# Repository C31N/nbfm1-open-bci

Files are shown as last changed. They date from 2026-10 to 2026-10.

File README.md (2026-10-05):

<!-- SPDX-License-Identifier: AGPL-3.0-only -->
# NBFM-1 Open BCI Stack






\n

Open-source research platform for a multimodal, non-invasive brain-computer interface built around three independently useful layers:

1. **NBFM-1** — an asynchronous neural foundation model with a millisecond-scale EEG/MEG fast path and a slower fNIRS context path.
2. **P1/P2 edge stack** — local inference, TensorRT/ONNX deployment, CUDA Graph-compatible I/O, encrypted local transport, intent gating, privacy zeroization, telemetry and systemd services.
3. **EEG128-TDM** — an ultra-low-cost 128-channel differential EEG acquisition architecture using paired 16:1 analog multiplexers, an 8-channel simultaneous-sampling delta-sigma ADC and an RP2040-class controller.

> **Research use only.** This repository does not claim medical-device certification, diagnostic suitability, prosthesis safety certification or validated free-form thought decoding. The `<5 ms` value is a compute-latency target measured after the required neural signal window is available, not a claim about neurophysiological response time.

## Defensive publication

The enabling technical disclosure is in [`PATENT_DISCLOSURE.md`](PATENT_DISCLOSURE.md). The document is intentionally explicit about timing, packet formats, signal routing, filter-settling handling, asynchronous multimodal fusion and privacy gating so the disclosed combinations can be independently implemented and searched as public technical literature.

A repository commit is evidence, not magic. For a stronger publication record, publish a signed release, generate the repository SHA-256 manifest and archive that release in a DOI-backed repository such as Zenodo. See [`docs/PUBLICATION_PROCEDURE.md`](docs/PUBLICATION_PROCEDURE.md).

## System architecture

```mermaid
flowchart LR
    EEG["128-ch EEG<br/>1 kHz after decimation"] --> FAST["Fast neural path"]
    MEG["OPM-MEG<br/>geometry embeddings"] --> FAST
    FNIRS["fNIRS<br/>20 Hz short/long separation"] --> SLOW["Slow context encoder"]
    FAST --> NBFM["NBFM-1 causal transformer"]
    SLOW --> XATTN["Cross-attention"]
    XATTN --> NBFM
    NBFM --> MOTOR["Motor Gaussian head<br/>mu + sigma"]
    NBFM --> GATE["Intent gate<br/>P(intent)"]
    NBFM --> CTC["Phonemic CTC head"]
    GATE --> PRIVACY["Local-first privacy gate"]
    CTC --> PRIVACY
    PRIVACY --> ENC["AES-256-GCM local export"]
    MOTOR --> SAFETY["Rate/uncertainty limiter"]
    ENC --> AGENT["Local agent adapter"]
    SAFETY --> ACT["Cursor / bench actuator interface"]
```

### EEG128-TDM acquisition path

```mermaid
flowchart LR
    E["128 differential EEG channels<br/>256 electrode conductors"] --> M["8 banks x paired 16:1 MUX<br/>16 CD74HC4067 total"]
    M --> B["16 low-noise unity buffers"]
    B --> A["ADS131M08<br/>8 simultaneous 24-bit delta-sigma channels<br/>32 kSPS"]
    A --> R["RP2040<br/>SPI + DMA"]
    R --> D["16-position demultiplex<br/>settling discard + averaging"]
    D --> O["128 channels x 250 SPS<br/>offset/gain correction"]
```

## Hardware revision status

The repository contains **EEG128-TDM Revision A0** KiCad/BOM/CPL/netlist sources, but A0 is **not released for fabrication or human-connected use**. The board still requires independent routing and footprint verification followed by clean KiCad 8 ERC/DRC and the safety release gates in [`docs/SAFETY_COMPLIANCE.md`](docs/SAFETY_COMPLIANCE.md).

The manufacturing exporter is fail-closed: [`hardware/eeg128-tdm/generate_manufacturing.py`](hardware/eeg128-tdm/generate_manufacturing.py) refuses to generate Gerber output while [`RELEASE_STATUS.json`](hardware/eeg128-tdm/RELEASE_STATUS.json) contains an unmet release gate.

## Privacy-state machine

```text
LOCKED --explicit local arm--> ARMED --P(intent) >= T_gate--> DECODING
   ^                          |                              |
   |                          +--below threshold------------+
   +---------------- timeout / lock / fault ----------------+
```

Speech logits remain local. When the gate is closed, the export tensor is replaced with a fixed-shape zero tensor before encryption. Frame dimensions therefore do not reveal whether a private speech hypothesis existed.

## Physical hardware release status

The repository contains the A0 KiCad project, logical netlist, BOM/CPL and fail-closed manufacturing tooling, but **A0 is not released for fabrication or human-connected use**.

The current audited EDA state has placement/net assignments but not completed copper routing, and the current schematic is a connectivity index rather than a complete instantiated circuit schematic. The authoritative release blockers are machine-readable in `hardware/eeg128-tdm/RELEASE_STATUS.json`.

Run:

```bash
python3 hardware/eeg128-tdm/validate_eda.py
```

Manufacturing export remains blocked until the independent physical release gates are satisfied.

See:

- `hardware/eeg128-tdm/EDA_AUDIT.md`
- `docs/SAFETY_COMPLIANCE.md`
- `docs/AUDIT_2026-10-05.md`

## Quick start

```bash
chmod +x deploy_bci_stack.sh
./deploy_bci_stack.sh
```

Run the latency auditor after inference and bridge services are healthy:

```bash
python3 bin/audit_latency.py \
  --json reports/latency-audit.json \
  --html reports/latency-audit.html
```

A benchmark is considered successful only when the measured P99 meets the configured threshold. The badge above states the **target**, not an unmeasured result.

## Licensing

Hardware design source and firmware are licensed under **CERN Open Hardware Licence Version 2 — Strongly Reciprocal (`CERN-OHL-S-2.0`)**. The NBFM-1 software architecture, inference stack, privacy gate, deployment code, scripts and project documentation are licensed under **GNU Affero General Public License v3.0 only (`AGPL-3.0-only`)**.

## Citation

Machine-readable citation metadata is in [`CITATION.cff`](CITATION.cff).

## Security

Neural raw data, derived embeddings, decoded speech, session keys, model weights and device-specific calibration can be sensitive. Never commit them. See [`SECURITY.md`](SECURITY.md) and the enforced exclusions in [`.gitignore`](.gitignore).

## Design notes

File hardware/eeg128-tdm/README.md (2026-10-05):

<!-- SPDX-License-Identifier: CERN-OHL-S-2.0 -->
# EEG128-TDM Hardware Source — Revision A0

## Architecture

```text
128 differential logical EEG channels
= 256 subject/electrode conductors
        |
        v
8 banks x 16 logical channels
        |
        v
16 paired CD74HC4067-class 16:1 multiplexers
        |
        v
16 TLV9064-class unity buffers
        |
        v
ADS131M08-class 8-channel simultaneous delta-sigma ADC
32 kSPS, external 8.192-MHz clock
        |
        v
RP2040 SPI1 + DMA
        |
        v
4 post-switch conversions discarded
4 late conversions averaged
        |
        v
128 logical channels x 250 SPS
```

## Source files

| File | Purpose |
|---|---|
| `design_spec.yaml` | Human-readable electrical/stack-up source of truth |
| `NETLIST.csv` | Detailed endpoint-to-endpoint logical connectivity |
| `BOM.csv` | JLCPCB/LCSC-oriented bill of materials |
| `CPL.csv` | JLCPCB-oriented component placement |
| `eeg128-tdm.kicad_sch` | KiCad 8 schematic/connectivity index |\n| `generate_schematic.py` | Deterministically generates a 640-component KiCad connectivity schematic from PCB pad/net assignments |
| `eeg128-tdm.kicad_pcb` | KiCad 8 four-layer A0 placement/net board |
| `eeg128-tdm.kicad_pro` | KiCad project |
| `validate_eda.py` | Source/BOM/CPL/net validation |
| `generate_manufacturing.py` | Fail-closed KiCad 8 ERC/DRC/Gerber/JLCPCB export |
| `RELEASE_STATUS.json` | Machine-readable fabrication/human-use release gates |

## Current fabrication status

**Revision A0 is not released for fabrication.**

The board source currently contains component placement and logical pad-to-net assignment for A0 design review, but the copper routing is not complete, the KiCad schematic is presently a connectivity index rather than a fully instantiated circuit schematic, and generated footprint land patterns have not been independently verified. `RELEASE_STATUS.json` therefore keeps `fabrication_release=false`.

This is intentional. A large human-connected mixed-signal board must not become orderable merely because source files exist.

The manufacturing exporter refuses to run until all release gates are true.

## Validation

Repository-level structural validation:

```bash
python3 hardware/eeg128-tdm/validate_eda.py
```

Release validation additionally requires KiCad CLI 8:

```bash
cd hardware/eeg128-tdm
python3 validate_eda.py --kicad-release-checks
```

After independent routing/footprint/safety review and only after `RELEASE_STATUS.json` is intentionally signed off:

```bash
python3 generate_manufacturing.py
```

The script executes KiCad ERC and PCB DRC before exporting Gerber, drill and position data. Any failed release gate or KiCad violation stops the export.

## Four-layer intent

```text
L1  F.Cu   analog inputs, MUX/buffer/ADC and short local digital routes
L2  In1.Cu continuous return plane; analog/digital domains managed by placement/current paths
L3  In2.Cu 3V3A / 3V3D / VCM distribution
L4  B.Cu   high-speed digital, USB and controller-side routing
```

Do not create arbitrary AGND/DGND moat cuts that force return currents to detour. Domain control is primarily by placement/routing, with the ground-domain connection deliberately reviewed at the ADC/power boundary.

## Safety

This is research hardware, not IEC 60601-certified equipment.

No human-connected use is authorized by this repository revision. Follow `docs/SAFETY_COMPLIANCE.md`. In particular, a subject-connected analog domain must not have an uncontrolled galvanic path to mains-referenced equipment.

## License

Hardware source is covered by `CERN-OHL-S-2.0`.

## Package and grounding audit

### ADS131M08IPBSR

Use the TI **PBS** mechanical drawing as the authoritative footprint reference. The package has a nominal 5 mm square body with 0.50 mm lead pitch and approximately 7 mm overall lead span. Distributor summaries can describe these dimensions differently; release review must use the manufacturer drawing.

### Ground plane

The current logical source uses separate `AGND` and `DGND` names while the intended PCB strategy calls for a continuous return plane. This conflict must be resolved before routing release. Do not introduce an arbitrary split-plane slot solely to preserve naming.

### Internal reference

The selected low-noise reference network must be reviewed explicitly before A0 fabrication. The present logical netlist records `ADC_REFIN` as unpopulated; for EEG noise optimization, provision for local REFIN filtering must be evaluated against TI guidance and the chosen converter mode.

See `EDA_AUDIT.md` and `RELEASE_STATUS.json`.

## Generated connectivity schematic

The deterministic generator can materialize every PCB/BOM component and every assigned pad net into a KiCad 8 schematic representation:

```bash
python3 generate_schematic.py
```

Default output:

```text
eeg128-tdm.generated.kicad_sch
```

It uses real component references and PCB pad numbers and emits local labeled wire stubs for assigned nets. It intentionally uses conservative generic passive-pin symbols. Therefore it is useful for reproducible connectivity review and schematic/PCB parity, but it does **not** replace manufacturer-symbol pin-type review or independently establish ERC/fabrication readiness.

Only after review may it replace the primary schematic:

```bash
python3 generate_schematic.py --replace-primary
```

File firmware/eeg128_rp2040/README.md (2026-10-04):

<!-- SPDX-License-Identifier: CERN-OHL-S-2.0 -->
# EEG128-TDM RP2040 Firmware

This firmware drives the Rev A0 EEG128-TDM acquisition concept:

- 8 differential ADC paths;
- 16 shared MUX addresses;
- ADS131M08-class converter at 32 kSPS;
- four conversions discarded after each MUX change;
- four late conversions averaged;
- 128 logical samples per frame at 250 frames/s;
- SPI1 + DMA acquisition;
- per-logical-channel startup offset calibration;
- binary 1152-byte P1/P2 packets with CRC32C.

## RP2040 pins

| Function | GPIO |
|---|---:|
| MUX A0..A3 | 2..5 |
| MUX enable | 6 |
| ADS DOUT / SPI1 RX | 8 |
| ADS CS | 9 |
| ADS SCLK / SPI1 SCK | 10 |
| ADS DIN / SPI1 TX | 11 |
| ADS DRDY | 12 |
| ADS SYNC/RESET | 13 |

The ADS clock is supplied by the board's dedicated 8.192-MHz CMOS oscillator.

## Build

```bash
export PICO_SDK_PATH=/path/to/pico-sdk
mkdir -p build
cd build
cmake ..
cmake --build . -j
```

The firmware is research firmware and does not authorize human-connected use. Follow `docs/SAFETY_COMPLIANCE.md`.

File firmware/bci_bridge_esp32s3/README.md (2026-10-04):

<!-- SPDX-License-Identifier: CERN-OHL-S-2.0 -->
# BCI Device Firmware

Firmware in this tree implements hardware acquisition/bridge functions, including deterministic sensor sampling, CRC32C framing, transport and device-side timing. It is licensed as hardware Source under `CERN-OHL-S-2.0`.

The bridge packet extension uses the common 128-byte BCI packet header plus a compact payload for low-cost test hardware. Production 128-channel acquisition uses the 4096-byte DMA-slot protocol disclosed in `PATENT_DISCLOSURE.md`.

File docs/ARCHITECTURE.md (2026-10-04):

<!-- SPDX-License-Identifier: AGPL-3.0-only -->
# Architecture Summary

## Fast path

EEG and OPM-MEG are sampled and preprocessed independently of the fNIRS hemodynamic timescale. Causal patch encoders produce aligned fast tokens. OPM-MEG tokens include sensor-pose embeddings.

## Slow context path

fNIRS remains at its native slow update rate. Long-separation and short-separation measurements feed a slow context encoder. Fast tokens cross-attend only to context already available at the inference timestamp.

## Decoder heads

NBFM-1 exposes a Gaussian motor head (`mu`, `log_sigma`), scalar intent gate and time-distributed CTC speech logits.

## Privacy boundary

Speech export requires both local `ARMED` state and an intent threshold. Closed-gate speech tensors are replaced by fixed-shape zero tensors before AEAD encryption. This avoids a message-length side channel.

## Hardware front end

The EEG128-TDM architecture maps eight 16-channel differential banks through sixteen paired analog multiplexers and sixteen buffers into eight simultaneous ADC inputs. At 32 kSPS, each 250 us slot contains enough conversions to discard digital-filter/analog settling and retain later conversions for the logical 250 SPS channel sample.

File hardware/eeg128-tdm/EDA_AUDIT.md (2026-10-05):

<!-- SPDX-License-Identifier: CERN-OHL-S-2.0 -->
# EEG128-TDM A0 EDA Release Audit

## Status

**NOT RELEASED FOR FABRICATION**

This document records the engineering state of the physical A0 source. It intentionally prevents “source exists” from being mistaken for “board is production-ready”.

## Current machine-observed source state

After deterministic materialization and native KiCad 8.0.9 validation on 2026-10-05:

```text
KiCad schematic:
  instantiated circuit symbols: 640
  electrical wire stubs:         1875
  primary schematic parses:      yes
  native netlist export:         yes

Native ERC report:
  total findings:                3338
  errors:                        183
  warnings:                      3155

KiCad PCB:
  footprints:                    640
  copper tracks/segments:        0
  vias:                          0
  copper zones:                  0
  four copper layers declared:   yes

Native PCB DRC report:
  unconnected errors:            499
  DRC violations:                1503
  DRC errors:                    897
  DRC warnings:                  606
  schematic-parity items:        0
```

The primary schematic is now a KiCad-loadable, deterministic 640-component connectivity schematic generated from the PCB pad/net assignments. It uses conservative generic passive pin types and therefore still requires manufacturer-symbol/pin-type review before `schematic_complete` can be set true.

The PCB remains a placement/net-assignment review artifact. It is not routed.

## A0 architecture retained

```text
256 electrode conductors
        |
        v
8 differential banks x 16 logical channels
        |
        v
16 x CD74HC4067
        |
        v
16 low-noise buffer channels
        |
        v
ADS131M08, 8 simultaneous differential channels
        |
        v
32 kSPS conversion stream
        |
        v
RP2040 SPI/DMA
        |
        v
settling discard + averaging
        |
        v
128 logical channels x 250 SPS
```

## ADS131M08 package

Part:

```text
ADS131M08IPBSR
TI package drawing: PBS
pins: 32
body: approximately 5 x 5 mm
lead pitch: 0.50 mm
outer lead span: approximately 7 x 7 mm
```

The project shall verify the footprint against the TI PBS mechanical drawing before setting `footprints_verified=true`.

## Grounding release decision

Current logical sources use `AGND` and `DGND` names while the layout strategy calls for a continuous return plane.

Before copper generation, the designer must resolve this explicitly. Preferred A0 direction:

- continuous low-impedance ground plane;
- analog and digital current control by placement and routing;
- no arbitrary split-plane slot under the ADC;
- decoupling return loops kept local;
- digital clocks kept out of the electrode/MUX region.

## REFIN decision

The internal-reference network shall be explicitly reviewed before A0 fabrication. For low-noise operation, provision for a local 100 nF REFIN capacitor to the converter ground reference should be evaluated against the selected ADS131M08 operating mode and TI guidance.

## Mandatory release evidence

The following evidence must exist before manufacturing export is enabled:

- schematic ERC report;
- PCB DRC report;
- schematic/PCB parity report;
- footprint verification record;
- placement/orientation review;
- Gerber visual review;
- BOM/CPL cross-check;
- routing-complete evidence;
- ground strategy review;
- isolated bench bring-up procedure;
- noise and settling test plan;
- signed `RELEASE_STATUS.json` change.

## Prohibited shortcuts

Do not:

- set release flags true merely to make CI green;
- export/order the current unrouted PCB;
- infer electrical correctness from the presence of pad net names;
- treat distributor footprint drawings as authoritative over manufacturer package drawings;
- connect a human subject while USB, bench supplies, oscilloscopes or other earth-referenced equipment provide an uncontrolled galvanic path.

## Native KiCad 8 audit interpretation

The successful GitHub Actions job means KiCad 8.0.9 can parse the EDA sources and produce native reports. It does **not** mean ERC or DRC are clean.

ERC finding classes include:

- endpoint-off-grid warnings;
- generated-library symbol warnings;
- unconnected-pin errors;
- dangling-label errors.

PCB findings are dominated by the intentionally unrouted design and generated-footprint review state, including unconnected items, clearance/shorting, solder-mask, silkscreen and library-footprint findings.

Therefore `erc_passed=false`, `drc_passed=false`, `routing_completed=false` and `fabrication_release=false` remain mandatory.

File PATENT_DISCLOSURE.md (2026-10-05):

<!-- SPDX-License-Identifier: AGPL-3.0-only -->
# Defensive Publication and Enabling Technical Disclosure — NBFM-1 Open BCI Stack

## 1. Purpose, scope and public-availability statement

This document is an enabling defensive publication of technical architectures, timing methods, signal-processing arrangements, machine-learning structures, privacy mechanisms and deployment methods for a non-invasive multimodal brain-computer interface.

**Initial document preparation date:** 2026-10-04.\n\n**Legal/technical audit revision:** 2026-10-05.

**Repository:** `C31N/nbfm1-open-bci`.

This document is intended to make the disclosed combinations publicly searchable and reproducible technical literature when the repository is publicly accessible without confidentiality restrictions.

For United States patent-law analysis, public availability before the effective filing date may be relevant under 35 U.S.C. 102(a)(1), including a printed publication or other disclosure available to the public. For European patent-law analysis, Article 54(2) EPC defines the state of the art as everything made available to the public before the filing date by written or oral description, use, or any other way. An alleged documentary disclosure must also teach the relevant technical subject matter sufficiently for the skilled person to carry it out.

This file therefore distinguishes:

1. **preparation date** — the date written above;
2. **public-availability evidence** — public Git commit, tag, release, archive, DOI or equivalent record; and
3. **technical enablement** — concrete parameters, relationships, timing and implementation details below.

No statement in this repository guarantees that every later patent application concerning related subject matter will be refused or invalidated. Patentability depends on the actual later claims, effective filing/priority dates, applicable law, novelty, inventive step/non-obviousness, enablement and evidence of public availability. The objective is to create strong, independently verifiable prior-art evidence for the specific teachings disclosed here.

Public disclosure may also limit or destroy the publishers' own future patent rights in jurisdictions without an applicable grace period. Publication should therefore occur only after any desired patent strategy has been decided.

## 2. Legal prior-art framework and evidentiary limits

### 2.1 United States — 35 U.S.C. §102

Under 35 U.S.C. §102(a)(1), a claimed invention may lack novelty where, before its effective filing date, it was patented, described in a printed publication, in public use, on sale, or otherwise available to the public.

The statute contains exceptions, including certain disclosures addressed by §102(b). Accordingly, this publication does **not** assert that its existence automatically defeats every later United States patent claim. The relevant questions include the later claim language, effective filing date, derivation/origin, public availability, and whether this disclosure actually teaches every element required by the claim.

Official text:

https://uscode.house.gov/view.xhtml?req=granuleid:USC-prelim-title35-section102

### 2.2 European Patent Convention — Article 54

Article 54(2) EPC defines the state of the art as everything made available to the public before filing by written or oral description, use, or any other way.

EPO examination guidance further states that:

- there is generally no restriction on the geographical location, language or manner of public availability;
- a written disclosure is publicly available when members of the public could obtain knowledge of its content without a confidentiality duty; and
- documentary prior art must provide sufficient information for the skilled person to put the disclosed technical teaching into practice.

Official sources:

- https://www.epo.org/en/legal/epc/2020/a54.html
- https://www.epo.org/en/legal/guidelines-epc/2026/g_iv_1.html
- https://www.epo.org/en/legal/guidelines-epc/2026/g_iv_2.html
- https://www.epo.org/en/legal/guidelines-epc/2026/g_iv_7_5.html

### 2.3 Internet-publication evidence

A public repository can be evidence of an internet disclosure, but the legal effect of any particular Git commit, release, archive or timestamp is fact-specific.

For that reason this project preserves multiple independent evidence layers:

1. public Git commit identity;
2. immutable release tag where available;
3. SHA-256 manifest of the disclosed files;
4. public release archive;
5. independent archival record/DOI where available.

A later technical correction should be published as a new revision and should not rewrite the historical record of the earlier disclosure.

### 2.4 What this publication is intended to establish

The purpose is to provide an enabling, searchable technical disclosure of the specific combinations described below — including asynchronous fast/slow neural fusion, intent-controlled fixed-shape zeroization, and settling-aware differential TDM EEG acquisition.

The publication is **not** a representation that:

- all conceivable variants have been disclosed;
- all later patent claims are necessarily anticipated or obvious;
- the authors have freedom to operate under third-party patents;
- public disclosure creates a patent right for the project;
- a particular patent office or court is bound to reach a specified result.

## 3. Terminology

The following project terms are used for searchability and do not imply exclusive trademark or patent rights:

- **NBFM-1** — Neural Brain Foundation Model, revision 1;
- **Fast Neural Path** — causal EEG and/or OPM-MEG processing;
- **Slow Context Path** — native-rate fNIRS context processing;
- **Intent Gate** — an explicit probability-gated privacy and control boundary;
- **Fixed-shape zeroization** — replacing sensitive logits with a same-shape zero tensor before export;
- **EEG128-TDM** — 128-channel differential time-division-multiplexed EEG front end.

---

# PART I — ASYNCHRONOUS MULTIMODAL NEURAL FOUNDATION MODEL

## 4. Sensor domains and asynchronous clocks

A representative system contains:

- 128-channel EEG, nominally 1 kHz after acquisition decimation;
- OPM-MEG channels carrying position/orientation metadata;
- fNIRS at approximately 20 Hz using long- and short-separation source-detector measurements.

The modalities are deliberately **not** resampled into one artificial common-rate stream before representation learning.

```text
EEG 1 kHz -----+
               +--> causal fast encoders --> fast tokens --------+
OPM-MEG -------+                                                   |
                                                                   +--> NBFM-1
fNIRS 20 Hz --> slow encoder --> persistent context --> XATTN ----+
                                                                   |
                          +----------------------------------------+-----------+
                          |                                        |           |
                          v                                        v           v
                 Gaussian motor head                         Intent gate   CTC speech
```

At fast-path inference timestamp `t`, the model may use only slow-context measurements with acquisition timestamps `<= t`.

## 5. Causal EEG/MEG patch encoding

Representative fast inputs are:

```text
EEG: [batch, 128, T_fast]
MEG: [batch, C_meg, T_fast]
```

A representative causal patch encoder uses:

```text
Conv1D: kernel 17, stride 8, left-only padding
normalization
GELU
Conv1D: kernel 5, stride 2, left-only padding
normalization
GELU
D_model = 384
```

For kernel length `k` and dilation `d`, left padding is:

```text
P_left = d * (k - 1)
```

No future fast sample contributes to the current output token.

## 6. OPM-MEG geometry conditioning

For sensor `i` use:

```text
g_i = (x_i, y_i, z_i, nx_i, ny_i, nz_i)
```

where the first three components are position and the latter three are measurement-axis orientation.

A sensor-level affine conditioning may be:

```text
(alpha_i, beta_i) = MLP(g_i)
x_i' = x_i * (1 + lambda * tanh(alpha_i)) + eta * beta_i
```

A token-level geometry embedding may additionally be:

```text
e_geometry = mean_i(MLP_geometry(g_i))
Z_MEG' = Z_MEG + e_geometry
```

This explicitly separates physical sensor geometry from arbitrary channel numbering.

## 7. Slow fNIRS context

A representative 20-Hz fNIRS context sample contains:

```text
128 long-separation paths x 2 wavelengths
32 short-separation paths x 2 wavelengths
= 320 scalar values
```

A causal slow encoder produces:

```text
Z_slow: [batch, N_slow, D_model]
```

The most recent valid context remains available until a new fNIRS sample arrives. The fast path does not fabricate intermediate hemodynamic observations.

## 8. Asynchronous fast-query/slow-context cross-attention

For each fusion block:

```text
Q = Wq * Z_fast
K = Wk * Z_slow
V = Wv * Z_slow

Attention = softmax((Q * transpose(K)) / sqrt(d_head))
Z_fast' = Z_fast + Attention * V
```

The disclosed feature is the use of native-rate slow context as persistent memory while fast causal tokens provide queries. This differs from mandatory upsampling/concatenation of fNIRS to every EEG/MEG sample.

## 9. Representative NBFM-1 edge model

```text
D_model        = 384
heads          = 6
layers         = 6..8
FF multiplier  = 4
fast context   = hundreds to thousands of samples
slow context   = independently sized fNIRS history
edge precision = FP16 or validated INT8
```

Each block contains:

```text
pre-norm
--> causal fast self-attention
--> residual
--> fast-query / slow-context cross-attention
--> residual
--> feed-forward network
--> residual
```

## 10. Self-supervised pretraining

Pretraining can combine:

- masked temporal reconstruction;
- masked channel reconstruction;
- modality masking;
- geometry perturbation;
- cross-modal prediction;
- subject-contrastive learning;
- covariance/domain alignment;
- teacher-student latent reconstruction.

Representative total objective:

```text
L_total =
    lambda_masked      * L_masked
  + lambda_crossmodal  * L_crossmodal
  + lambda_contrastive * L_contrastive
  + lambda_domain      * L_domain
  + lambda_task        * L_task
```

## 11. Gaussian motor-intent head

The motor head emits:

```text
mu       = [vx, vy, vz, grip]
log_std  = [sx, sy, sz, sgrip]
```

with diagonal Gaussian interpretation:

```text
p(y | X) = Normal(mu, diag(exp(2 * log_std)))
```

A separate safety stage may implement:

```text
if P(intent) > T_motor and every std < std_max:
    u_safe = clamp(mu)
else:
    u_safe = 0
```

The AI decoder therefore does not directly command an actuator without uncertainty and safety checks.

## 12. Dedicated intent gate

The intent head computes a scalar probability:

```text
p_intent = sigmoid(w^T z + b)
```

Representative speech/privacy threshold:

```text
T_gate = 0.95
```

The intent output is explicitly used as a **privacy/export boundary**, not solely as another classification metric.

---

# PART II — LOCAL-FIRST ZERO-SIDECHANNEL PRIVACY

## 13. State machine

```text
LOCKED
  |
  | explicit local arm
  v
ARMED
  |
  | P(intent) >= T_gate
  v
DECODING
```

A high neural probability alone cannot arm a locked device. Explicit lock, timeout, watchdog or authentication failure may return the device to `LOCKED`.

## 14. Fixed-shape speech-logit zeroization

Let speech logits have shape:

```text
L: [T_speech, vocabulary]
```

Export rule:

```text
if local_state permits decoding and P(intent) >= T_gate:
    L_export = L
    speech_valid = 1
else:
    L_export = zeros_like(L)
    speech_valid = 0
```

The **shape and serialized field layout remain unchanged**. Zeroization occurs before encryption and before the data leaves the local inference boundary.

This design reduces straightforward content-presence and message-length side channels.

## 15. Local-first processing

Default path:

```text
neural sensors
--> local preprocessing
--> local NBFM inference
--> local intent/privacy gate
--> same-shape zeroization when closed
--> authenticated encryption
--> local authenticated consumer
```

Raw EEG/MEG/fNIRS, latent embeddings and ungated speech logits do not require cloud transport.

## 16. Authenticated encrypted export

Representative implementation:

- AES-256-GCM;
- random 128-bit session ID;
- HKDF-SHA256 session-key derivation;
- 96-bit nonce = random 32-bit stream ID || monotonic 64-bit frame sequence;
- envelope authenticated as AEAD associated data;
- replay and sequence rollback rejected.

Representative key derivation:

```text
K_session = HKDF-SHA256(
    input_key_material = K_master,
    salt = session_id,
    info = "NBFM-1/local-export/v1",
    output_length = 32 bytes
)
```

The encrypted payload includes intent probability, speech-valid bit, motor mean/uncertainty, fixed tensor dimensions and fixed-shape speech logits.

## 17. Deterministic action boundary

CTC output is never interpreted as unrestricted shell text.

```text
CTC tokens
--> normalization
--> exact fixed allowlist mapping when possible
--> optional local LLM constrained to an enum-only JSON schema
--> confidence rejection
--> fixed action ID
--> code-side fixed handler
```

The language model cannot create shell strings, file paths, URLs, arbitrary motor parameters or new handlers.

---

# PART III — 128-CHANNEL DIFFERENTIAL EEG TDM FRONT END

## 18. Physical topology

Representative EEG128-TDM arrangement:

```text
128 logical differential channels
= 256 electrode conductors

8 banks x 16 differential channels
        |
        v
16 paired 16:1 analog multiplexers
(positive and negative MUX per bank)
        |
        v
16 low-noise unity buffers
        |
        v
8 simultaneous differential ADC channels
        |
        v
ADS131M08-class delta-sigma ADC at 32 kSPS
        |
        v
RP2040-class controller, SPI + DMA
        |
        v
settling-aware demultiplexing
        |
        v
128 logical channels x 250 SPS
```

A concrete implementation uses 16 CD74HC4067-class multiplexers, TLV9064-class buffers, one ADS131M08-class converter and an RP2040-class controller.

The component brands themselves are not asserted as novel; the disclosed architecture concerns their particular signal topology, synchronized differential switching, settling schedule and system integration.

## 19. Differential bank mapping

For bank `b = 0..7`:

```text
logical channels = 16*b .. 16*b+15

CH(16*b+0)+  --+
...              +--> MUX_P[b] --> buffer --> ADC[b].P
CH(16*b+15)+ --+

CH(16*b+0)-  --+
...              +--> MUX_N[b] --> buffer --> ADC[b].N
CH(16*b+15)- --+
```

All paired multiplexers share the same four address bits.

## 20. TDM timing

At 250 logical samples/s:

```text
T_frame = 1 / 250 s = 4 ms
T_slot  = 4 ms / 16 = 250 us
```

At 32 kSPS:

```text
T_conversion = 31.25 us
N_slot = 8 conversions per 250-us MUX slot
```

## 21. SINC3/digital-filter settling discard

Concrete implementation:

```text
0 us:
    disable/switch paired MUX address

approximately 2 us:
    enable MUX path
    issue ADC synchronization event

conversion 1: discard
conversion 2: discard
conversion 3: discard
conversion 4: discard
conversion 5: retain
conversion 6: retain
conversion 7: retain
conversion 8: retain

logical_sample =
    arithmetic_mean(conversion 5..8)

advance MUX address
repeat
```

Generalized rule:

```text
N_discard = ceil(
    (t_analog_settle + t_digital_filter_settle) / T_conversion
)

N_discard + N_keep <= N_slot

logical_sample =
    sum(samples[N_discard : N_discard + N_keep]) / N_keep
```

The 4-discard/4-retain schedule is a concrete embodiment for the 32-kSPS, 250-us slot configuration. Other component choices may require a different discard count calculated from measured and specified settling.

## 22. Multiplexing crosstalk controls

The architecture combines:

- differential P/N paths switched synchronously;
- break-before-make multiplexers;
- short matched MUX-to-buffer routes;
- no digital clock routing under electrode inputs;
- ADC synchronization following every MUX transition;
- explicit rejection of early conversions;
- averaging only settled late conversions;
- per-logical-channel offset/gain calibration.

## 23. Common-mode and driven reference

A representative implementation establishes `VCM` near mid-supply and uses dedicated common-mode sense electrodes plus an active driven-reference/DRL stage.

```text
V_DRL = V_CM - G_DRL * (V_CMS - V_CM)
```

The DRL reduces common-mode voltage presented to the acquisition path. It does **not** change the converter manufacturer's intrinsic CMRR specification.

A large series resistor limits current into the driven body electrode. Human-connected prototypes additionally require independently reviewed patient isolation and leakage-current controls.

## 24. Calibration

Each logical channel has:

```text
offset[channel]
gain[channel]
corrected = gain[channel] * (raw - offset[channel])
```

Startup averaging can estimate baseline offset. Precision voltage calibration should use a known injected calibration source.

---

# PART IV — PACKET, DMA AND ASYNCHRONOUS fNIRS FORMAT

## 25. Fixed DMA slot

Representative shared-memory slot:

```text
4096 bytes total

128-byte header
512-byte EEG int32[128]
512-byte MEG int32[128]
optional fNIRS sub-frame
unused remainder
```

Representative packet lengths:

```text
EEG+MEG only: 1152 bytes
EEG+MEG+fNIRS: 2456 bytes
DMA slot: 4096 bytes
```

## 26. Header fields

```text
uint32 magic
uint16 protocol_version
uint16 header_bytes
uint32 packet_bytes
uint32 sequence
uint64 timestamp_ns
uint32 flags
uint32 status
uint32 eeg_channel_mask[4]
uint32 meg_channel_mask[4]
channel counts
sample formats
reserved extension bytes
uint32 payload_crc32c
uint32 header_crc32c
```

Header size is fixed at 128 bytes. CRC uses CRC32C/Castagnoli. The header CRC excludes only its own field. Payload CRC covers bytes `header_bytes .. packet_bytes-1`.

## 27. Native-rate fNIRS sub-frame

A slow sub-frame is appended only when a new 20-Hz fNIRS sample exists.

```text
timestamp_ns
sample_index
long_channel_count = 128
short_channel_count = 32
wavelength_count = 2
sample_format
flags
long_intensity[128][2]
short_intensity[32][2]
```

This preserves asynchronous sensor timing in the transport itself.

---

# PART V — LOW-LATENCY EDGE DEPLOYMENT

## 28. Latency definition

The project target of `<5 ms` means **compute and local transport latency after the last sample required by the selected neural inference window has become available**.

It does not include the neural observation-window duration and does not imply millisecond fNIRS hemodynamics.

## 29. Deployment pipeline

```text
sensor or simulator
--> DMA/shared-memory ring
--> preprocessing
--> NBFM-1 TensorRT/ORT inference
--> intent/privacy gate
--> fixed-shape zeroization
--> AES-256-GCM
--> Unix-domain socket
--> deterministic control bridge
--> telemetry / bounded action sink
```

Representative static tensor shapes:

```text
EEG          [1, 128, 512]
MEG          [1, 128, 512]
MEG geometry [1, 128, 6]
fNIRS        [1, 320, 20]
```

Deployment may use persistent TensorRT contexts, page-locked host memory, persistent device allocations, named tensor addresses, asynchronous copies, `execute_async_v3`, engine/timing caches and CUDA Graph replay where supported.

## 30. Independent latency audit

A benchmark may inject synthetic packets into the same 4096-byte ring and measure:

```text
ring -> preprocessing -> inference -> privacy gate
     -> AEAD framing -> Unix socket -> bridge
```

Reports include P50, P99, P99.9, maximum, fraction below 5 ms, timestamp jitter and saturation throughput. A target is not reported as achieved unless the measured percentile passes.

---

# PART VI — COMBINED EMBODIMENTS AND EQUIVALENTS

## 31. Combined embodiments

**Embodiment A:** EEG128-TDM + OPM-MEG geometry + 20-Hz fNIRS + asynchronous NBFM-1 + Gaussian motor head + intent gate + fixed-shape zeroization + encrypted local transport + deterministic action router.

**Embodiment B:** EEG128-TDM + fNIRS slow context + the same asynchronous fusion/privacy path, with MEG omitted.

**Embodiment C:** synthetic DMA producer using the identical packet format, allowing the complete cryptographic/inference/control path to be tested without a connected subject.

## 32. Equivalent implementations

The teachings are not limited to example vendors. Equivalent embodiments include another low-leakage 16:1 MUX, another simultaneous delta-sigma ADC, FPGA or alternative MCU, ChaCha20-Poly1305 instead of AES-GCM, another edge accelerator instead of TensorRT, or another causal neural architecture preserving the described fast-query/slow-context relation.

---

# PART VII — PRIOR-ART EVIDENCE CHAIN

## 33. Recommended immutable evidence

For each defensive-publication release:

1. freeze an exact repository tree;
2. generate `PUBLICATION_SHA256SUMS`;
3. create a cryptographically signed commit and annotated signed tag where possible;
4. publish a public release from that immutable tag;
5. retain the public commit/tag/release timestamps;
6. archive the exact release in an independent repository such as Zenodo or another long-term archive;
7. retain the DOI/archive identifier;
8. do not rewrite or move the historical publication tag.

The SHA-256 manifest proves file identity relative to the released tree. It does not itself establish the legal publication date; public availability evidence does that.

## 34. Legal limitation

This disclosure is designed to be useful as prior art against later claims that are not novel or inventive/non-obvious over the teachings actually made public and enabled here.

It does **not** guarantee:

- refusal or invalidity of every later patent mentioning the same field;
- freedom to operate;
- ownership of all underlying intellectual property;
- that unrelated or narrower improvements cannot themselves be patented.

Patent analysis is claim-specific and jurisdiction-specific.

---

# PART VIII — SEARCHABLE DISCLOSURE SUMMARY

This publication expressly discloses, separately and in combination:

1. causal EEG/OPM-MEG fast tokens with native-rate fNIRS slow memory through asynchronous cross-attention;
2. OPM-MEG conditioning by sensor position and orientation;
3. shared representation with Gaussian motor, intent-gate and phonemic CTC heads;
4. use of intent probability as a neuro-privacy export boundary;
5. same-shape zeroization of sensitive speech logits before authenticated encryption;
6. constant speech tensor dimensions whether the gate is open or closed;
7. local-first neural processing without required raw-neural cloud transport;
8. enum-only deterministic action routing after probabilistic interpretation;
9. 128 differential EEG channels using eight banks of paired 16:1 multiplexers ahead of eight simultaneous differential ADC inputs;
10. 16-position, 250-us TDM scheduling from a 32-kSPS eight-channel ADC to 128 x 250-SPS logical channels;
11. synchronization after each MUX change followed by explicit digital-filter/analog-settling conversion discard;
12. the concrete four-discard/four-retain averaging schedule;
13. asynchronous fNIRS sub-frames present only when a new slow sample exists;
14. fixed 4096-byte DMA slots with nanosecond timestamps, masks and CRC32C;
15. static-shape FP16 TensorRT inference with persistent/pinned buffers and optional CUDA Graph replay;
16. synthetic DMA production in the identical binary format for full-stack validation;
17. percentile/jitter measurement of the ring-to-inference-to-privacy-to-socket path.

---

## 35. Safety and regulatory status

This publication describes research engineering. It does not assert medical-device certification, diagnostic suitability, clinical validation, patient electrical safety, validated free-form thought reading or certification for safety-critical actuator control.

Human-connected implementations require separate electrical-safety, EMC, biocompatibility, clinical, cybersecurity and regulatory assessment appropriate to their actual intended purpose and jurisdiction.

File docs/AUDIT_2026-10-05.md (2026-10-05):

<!-- SPDX-License-Identifier: AGPL-3.0-only -->
# Repository Release Audit — 2026-10-05

## Scope

This audit covers source completeness, licensing metadata, defensive-publication quality, CI/security automation, runtime software and the physical EEG128-TDM EDA source in `C31N/nbfm1-open-bci`.

It is a technical and repository-compliance audit, not a certification, patentability opinion, freedom-to-operate opinion, medical-device clearance or product-liability waiver.

## Executive status

| Area | Status | Release meaning |
|---|---|---|
| NBFM-1 software source | PASS | source present and testable |
| Privacy gate / secure stream | PASS | source present; unit tests present |
| REUSE 3.0 metadata | PASS at audited baseline | GitHub CI `reuse lint` passed |
| Ruff / Python syntax / pytest | PASS at audited baseline | GitHub CI passed |
| CodeQL | PASS at audited baseline | GitHub CodeQL workflow passed |
| Release SHA manifest | BLOCKED at audited baseline | manifest was missing/stale; corrected release workflow is required |
| Defensive publication | PASS with legal caveat | enabling disclosure strengthened; no guarantee against every later claim |
| Dual/multi-license boundary | PASS as path-scoped aggregate | no blanket cross-license compatibility conclusion for mixed derivatives |
| KiCad schematic | BLOCKED | current `.kicad_sch` is a connectivity index, not a complete component schematic |
| PCB copper routing | BLOCKED | current `.kicad_pcb` contains placement/net assignments but no routed copper/vias/zones |
| Gerber production export | FAIL-CLOSED | exporter intentionally refuses while release gates are false |
| Human-connected use | PROHIBITED | no IEC 60601/MDR/FDA clearance or patient-safety validation |

## Audited baseline

The audit began from public `main` commit:

`e9be76ca91a2e0fa963e361280f0d287fd6227e9`

At that commit, GitHub Actions showed:

- Python syntax: success
- Ruff: success
- pytest: success
- zero-debt gate: success
- `CITATION.cff` validation: success
- REUSE 3.0: success
- shell syntax: success
- release manifest: failure
- CodeQL: success

## EDA findings

### Schematic

The original primary schematic was not loadable by native KiCad 8. It has since been replaced by the deterministic 640-component connectivity schematic generated from PCB pad/net assignments. KiCad 8.0.9 now parses the primary source and exports a native netlist. The generated symbols deliberately use conservative generic passive pin types, so manufacturer-symbol and electrical-pin-type review remains required before schematic completion may be declared.

### PCB

The current PCB source contains component placement and pad-to-net assignment for the A0 review layout, but no completed copper routing, vias or copper zones. Native KiCad 8.0.9 DRC reports 499 unconnected errors and 1,503 DRC violations (897 errors, 606 warnings). Native ERC reports 3,338 findings (183 errors, 3,155 warnings).

Accordingly:

- `routing_completed=false`
- `fabrication_release=false`
- `human_connected_use_authorized=false`

must remain false.

### ADS131M08 package audit

The ADS131M08IPBSR uses TI package drawing **PBS**, a 32-pin TQFP. TI's mechanical drawing identifies a nominal 5 mm square body, 0.50 mm lead pitch, and approximately 7 mm outer lead span. The BOM description `TQFP-32_5x5mm_P0.5mm` is therefore not rejected merely because TI's product page also describes the package envelope as 7 mm × 7 mm.

Authoritative package verification shall use the TI PBS mechanical drawing, not only distributor metadata.

References:

- https://www.ti.com/product/ADS131M08
- https://www.ti.com/lit/ds/symlink/ads131m08.pdf
- https://www.ti.com/packaging/docs/carriermaterial/carrierlookup?OPN=ADS131M08IPBSR&state=details

### Grounding conflict

The design intent says the four-layer board should use a continuous return plane, but the logical source presently distinguishes `AGND` and `DGND`.

Before routing release, one explicit, reviewed grounding strategy is required:

1. a single continuous ground net/plane with analog/digital partitioning by placement and return-current control; or
2. an explicitly documented net-tie strategy whose location and impedance are reviewed.

No arbitrary ground-plane moat is permitted.

### Reference filtering

The design uses the ADS131M08 internal reference. TI characterizes the converter with a 100 nF capacitor at REFIN for internal-reference operation. TI support also notes that the capacitor filters bandgap noise and may be omitted for some modes/use cases.

For the low-noise EEG target, the A0 release review shall explicitly decide and document the REFIN network rather than leaving it as an accidental NC.

## Hardware release conditions

The A0 board shall not be exported as a fabrication release until all of the following are independently completed:

1. complete KiCad schematic with symbols, pins and electrical connectivity;
2. complete four-layer copper routing;
3. ground strategy resolved;
4. manufacturer land-pattern verification for every non-generic footprint;
5. BOM/CPL/PCB reference and orientation cross-check;
6. KiCad 8 ERC pass;
7. KiCad 8 DRC pass, including schematic parity;
8. Gerber/drill visual review;
9. isolated, current-limited bench bring-up without a human subject;
10. input-noise, settling, crosstalk, CMRR and fault-condition measurements;
11. safety review under `docs/SAFETY_COMPLIANCE.md`.

## Legal audit

### United States

35 U.S.C. §102(a)(1) can treat a claimed invention as prior art where, before the effective filing date, it was patented, described in a printed publication, in public use, on sale, or otherwise available to the public.

The statute also contains exceptions, including certain inventor-originated disclosures under §102(b). No repository statement should claim a universal automatic bar against every later U.S. patent claim.

Official source:

https://uscode.house.gov/view.xhtml?req=granuleid:USC-prelim-title35-section102

### European Patent Convention

Article 54(2) EPC includes everything made available to the public by written or oral description, use or any other way before filing. EPO guidance states that there is generally no geographic or language restriction, and documentary prior art must contain an enabling technical teaching.

Official sources:

- https://www.epo.org/en/legal/epc/2020/a54.html
- https://www.epo.org/en/legal/guidelines-epc/2026/g_iv_1.html
- https://www.epo.org/en/legal/guidelines-epc/2026/g_iv_2.html
- https://www.epo.org/en/legal/guidelines-epc/2026/g_iv_7_5.html

## Licensing audit

This repository is **not** “dual licensed” in the usual sense of offering the same work under two alternative licences.

It is a **path-scoped multi-license repository**:

- `hardware/**`, `firmware/**`: CERN-OHL-S-2.0
- host/model/privacy/deployment/documentation paths: AGPL-3.0-only

The two domains may coexist in one repository and interoperate through documented interfaces. That does not establish universal licence compatibility if source from both licences is copied into one derivative work.

The CERN OHL project identifies CERN-OHL-S as the strongly reciprocal v2 variant:

https://cern-ohl.web.cern.ch/

## Regulatory and safety audit

There is no blanket “FDA Class II/III exemption”.

FDA states that most Class I and **some** Class II devices are exempt from 510(k), subject to the classification regulation and other controls. Investigational device studies are separately governed by the IDE framework and risk classification.

Relevant official sources:

- https://www.fda.gov/medical-devices/classify-your-medical-device/class-i-and-class-ii-device-exemptions
- https://www.fda.gov/medical-devices/investigational-device-exemption-ide/ide-approval-process

EU MDR applicability depends materially on intended purpose and other scope provisions. Calling a repository “research only” does not override the actual intended purpose, labeling, promotion or use.

## Final audit rule

**Software publication readiness and PCB fabrication readiness are separate release gates.**

The software/defensive-publication repository can be publicly released while the physical A0 PCB remains explicitly unreleased for fabrication and prohibited for human connection.

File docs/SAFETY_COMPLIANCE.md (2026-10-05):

<!-- SPDX-License-Identifier: AGPL-3.0-only -->
# Hardware Safety, Human-Subject Use and Regulatory Compliance

## 1. Status of this project

The NBFM-1 Open BCI Stack and EEG128-TDM hardware are **research engineering prototypes**.

They are not represented as:

- CE-marked medical devices;
- MDR-conforming finished medical devices;
- FDA-cleared, FDA-approved or FDA-exempt finished devices;
- IEC 60601-1 certified medical electrical equipment;
- IEC 60601-1-2 certified EMC systems;
- ISO 14971-compliant risk-managed finished medical devices;
- IEC 62304-compliant medical-device software;
- IEC 62366-1 validated usability-engineered medical devices;
- clinically validated diagnostic or therapeutic systems.

The regulatory classification of any derivative depends on its **actual intended purpose, claims, users, patient population, risk and jurisdiction**. In the European Union, a product can fall under Regulation (EU) 2017/745 when the manufacturer's intended purpose is medical. Software classification can be affected by MDR Rule 11. In the United States, device classification and any 510(k), De Novo, PMA, IDE or exemption pathway must be determined for the actual device and intended use.

There is no blanket "FDA Class II/III exemption" for this project.

## 2. Mandatory research-prototype restrictions

When any electrode, DRL/reference electrode, fNIRS optode assembly or other conductive patient/subject interface is attached to a person, the following project rules apply.

### 2.1 Power

The patient-connected analog domain shall be powered only from an isolated battery-operated domain.

**Prohibited while a subject is connected:**

- charging the patient-connected battery from mains;
- connecting a non-isolated bench supply;
- connecting an earth-referenced oscilloscope or logic analyzer;
- connecting a desktop PC, powered USB hub or mains-powered SBC directly to the patient-connected USB/data domain;
- defeating protective resistors, isolation barriers or enclosure interlocks.

Disconnect the subject before charging, probing, programming or attaching non-isolated laboratory equipment.

### 2.2 USB/data isolation

A USB connection that crosses from a patient-connected battery domain to a mains-referenced host shall use a separately engineered isolation barrier.

An **ADuM3160-class USB isolator** may be used only as a research-prototype data-isolation component for USB low/full-speed links. The ADuM3160 family supports USB low/full speed, up to 12 Mbit/s, and provides a rated digital isolation barrier. It is **not, by itself, proof of IEC 60601-1 compliance**, a complete Means of Patient Protection, or a substitute for creepage/clearance, isolated power, leakage-current, dielectric-strength and system-level verification.

If a final design requires high-speed USB, use an isolation architecture explicitly designed for that data rate and re-run the complete safety analysis.

### 2.3 DRL / driven reference

The driven-reference output shall:

- include current-limiting impedance located close to the patient connector;
- default to a high-impedance/non-driving state on firmware reset, power loss or op-amp fault where practicable;
- have bounded loop bandwidth;
- be tested for oscillation and worst-case DC output;
- not be used to claim patient protection.

For prototype work, use at least one high-value series resistor in the driven electrode path; a production medical design should evaluate redundant current limiting and single-fault behavior under the applicable standard.

### 2.4 Electrode inputs

Each subject-contacting acquisition conductor shall include input-current limiting and ESD/transient design appropriate to the intended environment.

The present low-cost TDM architecture does not, merely by including high-value resistors, demonstrate compliance with IEC 60601 patient-leakage-current limits or defibrillation protection.

### 2.5 Mechanical and optical safety

For fNIRS derivatives:

- calculate optical irradiance and thermal rise at the skin;
- enforce LED/laser current limits in hardware where feasible;
- use only emitters suitable for the wavelength and power;
- perform skin-contact and thermal testing;
- assess applicable photobiological safety requirements.

For head-mounted assemblies:

- eliminate exposed conductive edges;
- strain-relieve all electrode leads;
- prevent connector pins from becoming accessible during use;
- evaluate mechanical pressure points and skin-contact materials.

## 3. Required isolation architecture for human-connected bench research

Minimum research topology:

```text
                       PATIENT-CONNECTED DOMAIN

electrodes
    |
input protection
    |
EEG128-TDM analog front end
    |
battery-only isolated power
    |
MCU / local acquisition
    |
    +---- isolated data barrier ----> non-isolated host
          e.g. engineered
          ADuM3160-class FS USB
          barrier where bandwidth
          is sufficient

NO galvanic mains path to the patient-connected side
```

A USB isolator does not isolate a separate charger, oscilloscope ground, shield bond or any other parallel path. Every conductive path must be included in the isolation analysis.

## 4. Release gates before any human-connected prototype

Before attaching a revision to a person, document and pass at minimum:

1. schematic ERC and PCB DRC;
2. visual inspection and continuity/short test;
3. power-rail current-limit startup;
4. isolated-domain verification;
5. measured DC resistance from every subject-contacting conductor to each powered rail and ground;
6. worst-case DRL/reference output test;
7. electrode fault/open/short tests;
8. battery-only operation test;
9. leakage-current measurements with suitable calibrated instrumentation;
10. ESD/transient review;
11. temperature rise test;
12. firmware watchdog/fail-safe test;
13. data-integrity/CRC test;
14. documented risk assessment and approval by the responsible laboratory/person.

For clinical investigation or medical-device development, these prototype checks are not substitutes for formal standards and regulatory processes.

## 5. Software/control safety

NBFM-1 output shall not directly energize a safety-critical actuator.

A physical actuator path shall contain a separate deterministic safety layer implementing, as appropriate:

- watchdog timeout;
- command freshness;
- velocity/force/torque limits;
- workspace/end-stop limits;
- uncertainty rejection;
- explicit enable/dead-man state;
- emergency stop;
- fail-to-zero behavior.

The local LLM/action-router path is constrained to enumerated action identifiers and shall not generate arbitrary shell commands or arbitrary actuator parameters.

## 6. Data and neuro-privacy safety

Treat the following as sensitive:

- raw EEG, MEG and fNIRS;
- derived embeddings/features;
- decoded speech or semantic labels;
- personalized model adapters;
- device/session keys;
- subject calibration data.

The default system is local-first. Sensitive speech logits are zeroized at fixed shape below the intent threshold before authenticated export. Security controls do not make the system legally compliant by themselves; applicable privacy, research-ethics and data-protection rules still apply.

## 7. Human research

Use on human subjects may require institutional/ethics review, informed consent and jurisdiction-specific approval even when the hardware is non-invasive.

In the United States, investigational device requirements depend on the study and device risk. Significant-risk device studies generally require FDA IDE approval in addition to IRB approval; non-significant-risk studies remain subject to abbreviated IDE requirements and IRB oversight.

Do not infer an exemption from the repository's research label.

## 8. Liability limitation

Open-source license warranty disclaimers apply only to the extent permitted by applicable law.

Nothing in this document:

- waives non-waivable product-liability, personal-injury or statutory rights;
- guarantees immunity for maintainers, manufacturers, integrators or users;
- transfers a manufacturer's regulatory obligations to upstream contributors;
- authorizes clinical or commercial deployment without required conformity work.

Any party manufacturing, modifying, integrating, marketing or using a derivative is responsible for determining and meeting the laws and standards applicable to that derivative and its intended purpose.

## 9. Production medical-device path

A party intending medical use should establish a formal regulatory and quality program including, as applicable:

- ISO 14971 risk management;
- IEC 60601-1 electrical safety;
- IEC 60601-1-2 EMC;
- IEC 62304 software lifecycle;
- IEC 62366-1 usability engineering;
- cybersecurity lifecycle and threat management;
- biocompatibility for patient-contact materials;
- clinical evaluation/investigation;
- EU MDR or applicable FDA submission/classification work.

The exact set depends on the product, market and intended purpose.

## 10. Authoritative regulatory references

This document intentionally avoids asserting a generic regulatory exemption.

### United States

FDA states that most Class I and some Class II devices may be exempt from premarket notification, subject to the applicable classification regulation and other controls. There is no blanket Class II exemption and no generic Class III exemption created by labeling a device as open-source or research hardware.

- FDA — Class I and Class II Device Exemptions:
  https://www.fda.gov/medical-devices/classify-your-medical-device/class-i-and-class-ii-device-exemptions
- FDA — Investigational Device Exemption approval process:
  https://www.fda.gov/medical-devices/investigational-device-exemption-ide/ide-approval-process
- FDA — IDE responsibilities:
  https://www.fda.gov/medical-devices/investigational-device-exemption-ide/ide-responsibilities

### European Union

Regulation (EU) 2017/745 applies according to its scope and the actual intended purpose of the product. Repository wording cannot override the manufacturer's or integrator's real intended purpose, labeling or promotional claims.

Official MDR text:

https://eur-lex.europa.eu/eli/reg/2017/745/oj

### USB isolation component limitation

Analog Devices specifies the ADuM3160 as a USB low/full-speed isolator supporting 1.5 Mbit/s and 12 Mbit/s with a 2.5 kV RMS isolation rating under its stated component approvals.

Component datasheet:

https://www.analog.com/media/en/technical-documentation/data-sheets/adum3160.pdf

Those component ratings do **not** establish IEC 60601-1 Means of Patient Protection for the assembled EEG system. Medical electrical equipment requires system-level insulation coordination, leakage-current, dielectric, creepage/clearance, power-isolation and single-fault evaluation.

## 11. Release prohibition

For repository revision A0:

```text
fabrication_release = false
human_connected_use_authorized = false
```

These values are mandatory until the physical release gates in
`hardware/eeg128-tdm/RELEASE_STATUS.json` have been independently completed.

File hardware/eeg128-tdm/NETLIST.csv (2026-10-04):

Net | Endpoint A | Endpoint B | Function
CH000_P_ELECTRODE | J1.1 | R257.1 | subject electrode to series protection
CH000_P_MUX | R257.2 | U1.9 | protected signal to mux input
CH000_P_MUX | R1.1 | U1.9 | 10M bias tap
VCM | R1.2 | VCM | electrode bias return
CH000_N_ELECTRODE | J1.17 | R258.1 | subject electrode to series protection
CH000_N_MUX | R258.2 | U2.9 | protected signal to mux input
CH000_N_MUX | R2.1 | U2.9 | 10M bias tap
VCM | R2.2 | VCM | electrode bias return
CH001_P_ELECTRODE | J1.2 | R259.1 | subject electrode to series protection
CH001_P_MUX | R259.2 | U1.8 | protected signal to mux input
CH001_P_MUX | R3.1 | U1.8 | 10M bias tap
VCM | R3.2 | VCM | electrode bias return
CH001_N_ELECTRODE | J1.18 | R260.1 | subject electrode to series protection
CH001_N_MUX | R260.2 | U2.8 | protected signal to mux input
CH001_N_MUX | R4.1 | U2.8 | 10M bias tap
VCM | R4.2 | VCM | electrode bias return
CH002_P_ELECTRODE | J1.3 | R261.1 | subject electrode to series protection
CH002_P_MUX | R261.2 | U1.7 | protected signal to mux input
CH002_P_MUX | R5.1 | U1.7 | 10M bias tap
VCM | R5.2 | VCM | electrode bias return
CH002_N_ELECTRODE | J1.19 | R262.1 | subject electrode to series protection
CH002_N_MUX | R262.2 | U2.7 | protected signal to mux input
CH002_N_MUX | R6.1 | U2.7 | 10M bias tap
VCM | R6.2 | VCM | electrode bias return
CH003_P_ELECTRODE | J1.4 | R263.1 | subject electrode to series protection
CH003_P_MUX | R263.2 | U1.6 | protected signal to mux input
CH003_P_MUX | R7.1 | U1.6 | 10M bias tap
VCM | R7.2 | VCM | electrode bias return
CH003_N_ELECTRODE | J1.20 | R264.1 | subject electrode to series protection
CH003_N_MUX | R264.2 | U2.6 | protected signal to mux input
CH003_N_MUX | R8.1 | U2.6 | 10M bias tap
VCM | R8.2 | VCM | electrode bias return
CH004_P_ELECTRODE | J1.5 | R265.1 | subject electrode to series protection
CH004_P_MUX | R265.2 | U1.5 | protected signal to mux input
CH004_P_MUX | R9.1 | U1.5 | 10M bias tap
VCM | R9.2 | VCM | electrode bias return
CH004_N_ELECTRODE | J1.21 | R266.1 | subject electrode to series protection
CH004_N_MUX | R266.2 | U2.5 | protected signal to mux input
CH004_N_MUX | R10.1 | U2.5 | 10M bias tap
VCM | R10.2 | VCM | electrode bias return
CH005_P_ELECTRODE | J1.6 | R267.1 | subject electrode to series protection
CH005_P_MUX | R267.2 | U1.4 | protected signal to mux input
CH005_P_MUX | R11.1 | U1.4 | 10M bias tap
VCM | R11.2 | VCM | electrode bias return
CH005_N_ELECTRODE | J1.22 | R268.1 | subject electrode to series protection
CH005_N_MUX | R268.2 | U2.4 | protected signal to mux input
CH005_N_MUX | R12.1 | U2.4 | 10M bias tap
VCM | R12.2 | VCM | electrode bias return
CH006_P_ELECTRODE | J1.7 | R269.1 | subject electrode to series protection
CH006_P_MUX | R269.2 | U1.3 | protected signal to mux input
CH006_P_MUX | R13.1 | U1.3 | 10M bias tap
VCM | R13.2 | VCM | electrode bias return
CH006_N_ELECTRODE | J1.23 | R270.1 | subject electrode to series protection
CH006_N_MUX | R270.2 | U2.3 | protected signal to mux input
CH006_N_MUX | R14.1 | U2.3 | 10M bias tap
VCM | R14.2 | VCM | electrode bias return
CH007_P_ELECTRODE | J1.8 | R271.1 | subject electrode to series protection
CH007_P_MUX | R271.2 | U1.2 | protected signal to mux input
CH007_P_MUX | R15.1 | U1.2 | 10M bias tap
VCM | R15.2 | VCM | electrode bias return
CH007_N_ELECTRODE | J1.24 | R272.1 | subject electrode to series protection
CH007_N_MUX | R272.2 | U2.2 | protected signal to mux input
CH007_N_MUX | R16.1 | U2.2 | 10M bias tap
VCM | R16.2 | VCM | electrode bias return
CH008_P_ELECTRODE | J1.9 | R273.1 | subject electrode to series protection
CH008_P_MUX | R273.2 | U1.23 | protected signal to mux input
CH008_P_MUX | R17.1 | U1.23 | 10M bias tap
VCM | R17.2 | VCM | electrode bias return
CH008_N_ELECTRODE | J1.25 | R274.1 | subject electrode to series protection
CH008_N_MUX | R274.2 | U2.23 | protected signal to mux input
CH008_N_MUX | R18.1 | U2.23 | 10M bias tap
VCM | R18.2 | VCM | electrode bias return
CH009_P_ELECTRODE | J1.10 | R275.1 | subject electrode to series protection
CH009_P_MUX | R275.2 | U1.22 | protected signal to mux input
CH009_P_MUX | R19.1 | U1.22 | 10M bias tap
VCM | R19.2 | VCM | electrode bias return
CH009_N_ELECTRODE | J1.26 | R276.1 | subject electrode to series protection
CH009_N_MUX | R276.2 | U2.22 | protected signal to mux input
CH009_N_MUX | R20.1 | U2.22 | 10M bias tap
VCM | R20.2 | VCM | electrode bias return
CH010_P_ELECTRODE | J1.11 | R277.1 | subject electrode to series protection
CH010_P_MUX | R277.2 | U1.21 | protected signal to mux input
CH010_P_MUX | R21.1 | U1.21 | 10M bias tap
VCM | R21.2 | VCM | electrode bias return
CH010_N_ELECTRODE | J1.27 | R278.1 | subject electrode to series protection
CH010_N_MUX | R278.2 | U2.21 | protected signal to mux input
CH010_N_MUX | R22.1 | U2.21 | 10M bias tap
VCM | R22.2 | VCM | electrode bias return
CH011_P_ELECTRODE | J1.12 | R279.1 | subject electrode to series protection
CH011_P_MUX | R279.2 | U1.20 | protected signal to mux input
CH011_P_MUX | R23.1 | U1.20 | 10M bias tap
VCM | R23.2 | VCM | electrode bias return
CH011_N_ELECTRODE | J1.28 | R280.1 | subject electrode to series protection
CH011_N_MUX | R280.2 | U2.20 | protected signal to mux input
CH011_N_MUX | R24.1 | U2.20 | 10M bias tap
VCM | R24.2 | VCM | electrode bias return
CH012_P_ELECTRODE | J1.13 | R281.1 | subject electrode to series protection
CH012_P_MUX | R281.2 | U1.19 | protected signal to mux input
CH012_P_MUX | R25.1 | U1.19 | 10M bias tap
VCM | R25.2 | VCM | electrode bias return
CH012_N_ELECTRODE | J1.29 | R282.1 | subject electrode to series protection
CH012_N_MUX | R282.2 | U2.19 | protected signal to mux input
CH012_N_MUX | R26.1 | U2.19 | 10M bias tap
VCM | R26.2 | VCM | electrode bias return
CH013_P_ELECTRODE | J1.14 | R283.1 | subject electrode to series protection
CH013_P_MUX | R283.2 | U1.18 | protected signal to mux input
CH013_P_MUX | R27.1 | U1.18 | 10M bias tap
VCM | R27.2 | VCM | electrode bias return
CH013_N_ELECTRODE | J1.30 | R284.1 | subject electrode to series protection
CH013_N_MUX | R284.2 | U2.18 | protected signal to mux input
CH013_N_MUX | R28.1 | U2.18 | 10M bias tap
VCM | R28.2 | VCM | electrode bias return
CH014_P_ELECTRODE | J1.15 | R285.1 | subject electrode to series protection
CH014_P_MUX | R285.2 | U1.17 | protected signal to mux input
CH014_P_MUX | R29.1 | U1.17 | 10M bias tap
VCM | R29.2 | VCM | electrode bias return
CH014_N_ELECTRODE | J1.31 | R286.1 | subject electrode to series protection
CH014_N_MUX | R286.2 | U2.17 | protected signal to mux input
CH014_N_MUX | R30.1 | U2.17 | 10M bias tap
VCM | R30.2 | VCM | electrode bias return
CH015_P_ELECTRODE | J1.16 | R287.1 | subject electrode to series protection
CH015_P_MUX | R287.2 | U1.16 | protected signal to mux input
CH015_P_MUX | R31.1 | U1.16 | 10M bias tap
VCM | R31.2 | VCM | electrode bias return
CH015_N_ELECTRODE | J1.32 | R288.1 | subject electrode to series protection
CH015_N_MUX | R288.2 | U2.16 | protected signal to mux input
CH015_N_MUX | R32.1 | U2.16 | 10M bias tap
VCM | R32.2 | VCM | electrode bias return
BANK0_P_MUX_OUT | U1.1 | U17.3 | mux common to voltage follower
BANK0_P_BUFFER | U17.1 | U17.2 | unity follower feedback
BANK0_P_BUFFER | U17.1 | R513.1 | buffer output to ADC isolation resistor
ADC0_P | R513.2 | U21.29 | ADS131M08 differential input
BANK0_N_MUX_OUT | U2.1 | U17.5 | mux common to voltage follower
BANK0_N_BUFFER | U17.7 | U17.6 | unity follower feedback
BANK0_N_BUFFER | U17.7 | R514.1 | buffer output to ADC isolation resistor
ADC0_N | R514.2 | U21.30 | ADS131M08 differential input
CH016_P_ELECTRODE | J2.1 | R289.1 | subject electrode to series protection
CH016_P_MUX | R289.2 | U3.9 | protected signal to mux input
CH016_P_MUX | R33.1 | U3.9 | 10M bias tap
VCM | R33.2 | VCM | electrode bias return
CH016_N_ELECTRODE | J2.17 | R290.1 | subject electrode to series protection
CH016_N_MUX | R290.2 | U4.9 | protected signal to mux input
CH016_N_MUX | R34.1 | U4.9 | 10M bias tap
VCM | R34.2 | VCM | electrode bias return
CH017_P_ELECTRODE | J2.2 | R291.1 | subject electrode to series protection
CH017_P_MUX | R291.2 | U3.8 | protected signal to mux input
CH017_P_MUX | R35.1 | U3.8 | 10M bias tap
VCM | R35.2 | VCM | electrode bias return
CH017_N_ELECTRODE | J2.18 | R292.1 | subject electrode to series protection
CH017_N_MUX | R292.2 | U4.8 | protected signal to mux input
CH017_N_MUX | R36.1 | U4.8 | 10M bias tap
VCM | R36.2 | VCM | electrode bias return
CH018_P_ELECTRODE | J2.3 | R293.1 | subject electrode to series protection
CH018_P_MUX | R293.2 | U3.7 | protected signal to mux input
CH018_P_MUX | R37.1 | U3.7 | 10M bias tap
VCM | R37.2 | VCM | electrode bias return
CH018_N_ELECTRODE | J2.19 | R294.1 | subject electrode to series protection
CH018_N_MUX | R294.2 | U4.7 | protected signal to mux input
CH018_N_MUX | R38.1 | U4.7 | 10M bias tap
VCM | R38.2 | VCM | electrode bias return
CH019_P_ELECTRODE | J2.4 | R295.1 | subject electrode to series protection
CH019_P_MUX | R295.2 | U3.6 | protected signal to mux input
CH019_P_MUX | R39.1 | U3.6 | 10M bias tap
VCM | R39.2 | VCM | electrode bias return
CH019_N_ELECTRODE | J2.20 | R296.1 | subject electrode to series protection
CH019_N_MUX | R296.2 | U4.6 | protected signal to mux input
CH019_N_MUX | R40.1 | U4.6 | 10M bias tap
VCM | R40.2 | VCM | electrode bias return
CH020_P_ELECTRODE | J2.5 | R297.1 | subject electrode to series protection
CH020_P_MUX | R297.2 | U3.5 | protected signal to mux input
CH020_P_MUX | R41.1 | U3.5 | 10M bias tap
VCM | R41.2 | VCM | electrode bias return
CH020_N_ELECTRODE | J2.21 | R298.1 | subject electrode to series protection
CH020_N_MUX | R298.2 | U4.5 | protected signal to mux input
CH020_N_MUX | R42.1 | U4.5 | 10M bias tap
VCM | R42.2 | VCM | electrode bias return
CH021_P_ELECTRODE | J2.6 | R299.1 | subject electrode to series protection
CH021_P_MUX | R299.2 | U3.4 | protected signal to mux input
CH021_P_MUX | R43.1 | U3.4 | 10M bias tap
VCM | R43.2 | VCM | electrode bias return
CH021_N_ELECTRODE | J2.22 | R300.1 | subject electrode to series protection
CH021_N_MUX | R300.2 | U4.4 | protected signal to mux input
CH021_N_MUX | R44.1 | U4.4 | 10M bias tap
VCM | R44.2 | VCM | electrode bias return
CH022_P_ELECTRODE | J2.7 | R301.1 | subject electrode to series protection
CH022_P_MUX | R301.2 | U3.3 | protected signal to mux input
CH022_P_MUX | R45.1 | U3.3 | 10M bias tap
VCM | R45.2 | VCM | electrode bias return
CH022_N_ELECTRODE | J2.23 | R302.1 | subject electrode to series protection
CH022_N_MUX | R302.2 | U4.3 | protected signal to mux input
CH022_N_MUX | R46.1 | U4.3 | 10M bias tap
VCM | R46.2 | VCM | electrode bias return
CH023_P_ELECTRODE | J2.8 | R303.1 | subject electrode to series protection
CH023_P_MUX | R303.2 | U3.2 | protected signal to mux input
CH023_P_MUX | R47.1 | U3.2 | 10M bias tap
VCM | R47.2 | VCM | electrode bias return
CH023_N_ELECTRODE | J2.24 | R304.1 | subject electrode to series protection
CH023_N_MUX | R304.2 | U4.2 | protected signal to mux input
CH023_N_MUX | R48.1 | U4.2 | 10M bias tap
VCM | R48.2 | VCM | electrode bias return
CH024_P_ELECTRODE | J2.9 | R305.1 | subject electrode to series protection
CH024_P_MUX | R305.2 | U3.23 | protected signal to mux input
CH024_P_MUX | R49.1 | U3.23 | 10M bias tap
VCM | R49.2 | VCM | electrode bias return
CH024_N_ELECTRODE | J2.25 | R306.1 | subject electrode to series protection
CH024_N_MUX | R306.2 | U4.23 | protected signal to mux input
CH024_N_MUX | R50.1 | U4.23 | 10M bias tap
VCM | R50.2 | VCM | electrode bias return
CH025_P_ELECTRODE | J2.10 | R307.1 | subject electrode to series protection
CH025_P_MUX | R307.2 | U3.22 | protected signal to mux input
CH025_P_MUX | R51.1 | U3.22 | 10M bias tap
VCM | R51.2 | VCM | electrode bias return
CH025_N_ELECTRODE | J2.26 | R308.1 | subject electrode to series protection
CH025_N_MUX | R308.2 | U4.22 | protected signal to mux input
CH025_N_MUX | R52.1 | U4.22 | 10M bias tap
VCM | R52.2 | VCM | electrode bias return
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

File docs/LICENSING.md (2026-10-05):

<!-- SPDX-License-Identifier: AGPL-3.0-only -->
# Path-Scoped Multi-License and License-Boundary Audit

## 1. Repository license map

### CERN-OHL-S-2.0

Covered source:

```text
hardware/**
firmware/**
```

This project intentionally selects **CERN Open Hardware Licence Version 2 — Strongly Reciprocal**, SPDX identifier:

```text
CERN-OHL-S-2.0
```

### AGPL-3.0-only

Covered source:

```text
bin/**
software/**
scripts/**
systemd/**
config/**
.github/**
docs/**
tests/**
deploy_bci_stack.sh
README.md
PATENT_DISCLOSURE.md
SECURITY.md
CONTRIBUTING.md
NOTICE.md
CITATION.cff
```

SPDX identifier:

```text
AGPL-3.0-only
```

## 2. Why the two licenses can coexist

The repository is a path-scoped multi-license aggregate with an explicit architectural boundary. This is not dual licensing of the same work under two alternative licences.

The CERN-OHL-S-covered hardware/firmware domain and AGPL-covered host/inference domain communicate through documented hardware/protocol interfaces such as:

- USB CDC / serial framing;
- the 128-byte packet header;
- CRC32C-protected frames;
- the 4096-byte DMA/shared-memory slot;
- local encrypted socket framing.

Mere interoperability across such an interface does not require declaring the entire repository to be under one single license.

Each covered work must independently satisfy its own license when conveyed, modified or distributed.

## 3. Strong reciprocity boundary

CERN-OHL-S-2.0 is the **strongly reciprocal** CERN OHL v2 variant.

Contributors shall not assume it is permissive. Modifications to covered hardware Source and other material falling within the licence's reciprocal scope must be handled under CERN-OHL-S-2.0 as required by that licence.

## 4. AGPL network obligations

AGPL-3.0-only applies to the covered software. A modified AGPL-covered program that users interact with remotely through a network can trigger the AGPL section 13 corresponding-source requirement.

Do not remove the network-source obligation by placing the software behind a proprietary web/API layer.

## 5. Cross-copying rule

Do not copy implementation source from an AGPL-covered file into a CERN-OHL-S-covered file, or vice versa, merely because both live in this repository.

Before intentionally combining code/source into a single derivative work:

1. identify the source licence of every copied element;
2. determine whether the resulting work can satisfy all applicable terms;
3. preserve notices and complete corresponding/source requirements;
4. obtain legal review for non-trivial mixed derivatives.

Protocol definitions, numeric constants, factual pin mappings and independently reimplemented interface descriptions should still retain appropriate attribution/notices where copyrightable expression is copied.

## 6. Firmware classification

The project intentionally treats device/bridge firmware under `firmware/**` as part of the open hardware Source and licenses it under CERN-OHL-S-2.0.

Host-side Python, deployment services and model/inference code remain AGPL-3.0-only.

If firmware is later linked against third-party libraries, verify the third-party library terms separately.

## 7. Third-party dependencies

No repository notice relicenses:

- TensorRT/CUDA;
- PyTorch;
- ONNX Runtime;
- Arduino cores/SDKs;
- Pico SDK;
- Ollama;
- vendor datasheets/reference designs;
- externally sourced KiCad symbols/footprints;
- pretrained model weights.

Third-party components retain their upstream licences.

## 8. REUSE metadata

REUSE metadata is authoritative for per-path machine-readable attribution.

The root `.reuse/dep5` contains:

- a repository-wide AGPL default stanza; and
- a more specific `hardware/* firmware/*` CERN-OHL-S stanza.

The canonical full licence texts are stored under `LICENSES/`.

The CI runs:

```bash
reuse lint
```

and treats any missing licence/copyright association as a release failure.

## 9. No patent licence expansion

Copyright/open-hardware licensing and prior-art publication are distinct.

The licences grant only the rights actually stated in their terms. The defensive publication is evidence of disclosed technical teaching; it is not a blanket patent licence from unknown third parties and not a freedom-to-operate opinion.

## 10. Compatibility conclusion

For the repository as presently structured, no licence conflict is created merely by storing the separately licensed works together or by allowing them to communicate through documented protocol/hardware interfaces.

This conclusion does **not** mean that CERN-OHL-S-2.0 and AGPL-3.0-only are universally interchangeable or that arbitrary source-code mixing is automatically permitted. A combined derivative that incorporates copyrightable source from both scopes must be reviewed against both licences and any third-party terms.

The safe project rule is therefore:

```text
hardware/** + firmware/**          -> CERN-OHL-S-2.0
host/model/privacy/deployment code -> AGPL-3.0-only
cross-boundary interaction         -> documented protocol/interface
source copying across boundary     -> legal review before merge
```

CERN identifies CERN-OHL-S as its strongly reciprocal v2 variant:

https://cern-ohl.web.cern.ch/

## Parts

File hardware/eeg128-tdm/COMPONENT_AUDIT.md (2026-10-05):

<!-- SPDX-License-Identifier: CERN-OHL-S-2.0 -->
# Component and Assembly Source Audit — 2026-10-05

This document records identity checks for the A0 BOM. It is not a purchasing guarantee: stock, price, lifecycle and JLCPCB basic/extended classification can change at any time.

## Critical active components

| Ref | Manufacturer part | LCSC | Package used in BOM | Audit |
|---|---|---:|---|---|
| U1-U16 | TI CD74HC4067M96 | C496123 | SOIC-24-300mil | identity/package confirmed |
| U17-U20 | TI TLV9064IPWR | C779410 | TSSOP-14 | identity confirmed |
| U21 | TI ADS131M08IPBSR | C2862610 | TQFP-32, 5 mm body, 0.50 mm pitch | identity confirmed; verify against TI PBS drawing |
| U22 | TI OPA4171AIPWR | C529553 | TSSOP-14 | identity/package confirmed |
| U23 | Raspberry Pi RP2040 | C2040 | LQFN-56 7x7 | identity/package confirmed |
| U24 | TI TPS7A2033PDBVR | C2862740 | SOT-23-5 | identity/package confirmed |
| U25 | Diodes AP2112K-3.3TRG1 | C51118 | SOT-25-5 | identity/package confirmed |
| U26 | Winbond W25Q16JVSSIQ | C82317 | SOIC-8-208mil | identity/package confirmed |
| U27 | YXC OT2JI-111-8.192M | C7425393 | SMD3225-4P | identity/package confirmed |
| J1-J8 | HDGC 0.5K-QX-32PWB | C2919488 | 32P, 0.5 mm, right-angle FPC | identity/package confirmed |
| J9 | Korean Hroparts TYPE-C-31-M-12 | C165948 | USB-C 16P SMD | identity confirmed |
| J10 | JST S4B-PH-SM4-TB(LF)(SN) | C265102 | PH 4P, 2 mm, right angle | identity confirmed |
| J11 | JST S2B-PH-SM4-TB(LF)(SN) | C295747 | PH 2P, 2 mm, right angle | identity confirmed |
| Y1 | YXC X322512MSB4SI | C9002 | SMD3225-4P | identity/package confirmed |

## High-count input resistors

| Function | Manufacturer part | LCSC | Quantity/board | Audit |
|---|---|---:|---:|---|
| 10 MΩ electrode bias | Vishay RCS060310M0FKEA | C2092526 | 256 | identity/value/package confirmed |
| 100 kΩ series protection | UNI-ROYAL TC0325F1003T5F | C2989131 | 256 | identity/value/package confirmed |

These two line items dominate passive count and materially affect board cost and placement density.

## Manufacturer/distributor source hierarchy

Release verification shall use this precedence:

1. manufacturer datasheet and mechanical package drawing;
2. manufacturer product/package page;
3. JLCPCB/LCSC assembly record;
4. project BOM/CPL.

If a distributor description conflicts with a manufacturer mechanical drawing, the manufacturer drawing controls the footprint decision.

## Live-source references

- ADS131M08: https://www.ti.com/product/ADS131M08
- ADS131M08 datasheet: https://www.ti.com/lit/ds/symlink/ads131m08.pdf
- C2862610: https://www.lcsc.com/product-image/C2862610.html
- C496123: https://www.lcsc.com/product-detail/C496123.html
- C779410: https://www.lcsc.com/product-image/C779410.html
- C2040: https://www.lcsc.com/product-detail/C2040.html
- C82317: https://www.lcsc.com/product-detail/C82317.html
- C2092526: https://www.lcsc.com/product-detail/C2092526.html
- C2989131: https://www.lcsc.com/product-detail/C2989131.html
- C7425393: https://www.lcsc.com/product-detail/Oscillators_Yangxing-Tech-OT2JI-111-8-192M_C7425393.html
- C2919488: https://www.lcsc.com/product-detail/C2919488.html

## Cost target

The **< EUR 50 component-BOM target remains a target, not a guaranteed purchase quote**. The largest cost risks are:

- 512 high-count electrode resistors;
- 16 analog MUXes;
- the ADS131M08;
- electrode connectors;
- assembly surcharges for extended parts.

A manufacturing release must use a dated JLCPCB/LCSC quote at the intended production quantity. PCB fabrication, stencil, assembly setup, feeder/extended-part charges, shipping, VAT, isolation hardware and the electrode cap are not included in the component-BOM target unless a release explicitly says otherwise.

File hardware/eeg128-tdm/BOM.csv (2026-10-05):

Comment | Designator | Footprint | LCSC Part # | Manufacturer | Manufacturer Part # | Qty
16:1 analog multiplexer | U1,U2,U3,U4,U5,U6,U7,U8,U9,U10,U11,U12,U13,U14,U15,U16 | SOIC-24_7.5x15.4mm_P1.27mm | C496123 | Texas Instruments | CD74HC4067M96 | 16
Quad RRIO buffer | U17,U18,U19,U20 | TSSOP-14_4.4x5mm_P0.65mm | C779410 | Texas Instruments | TLV9064IPWR | 4
8ch 24-bit delta-sigma ADC | U21 | TQFP-32_5x5mm_P0.5mm | C2862610 | Texas Instruments | ADS131M08IPBSR | 1
Quad DRL/VCM op amp | U22 | TSSOP-14_4.4x5mm_P0.65mm | C529553 | Texas Instruments | OPA4171AIPWR | 1
Microcontroller | U23 | QFN-56_7x7mm_P0.4mm | C2040 | Raspberry Pi | RP2040 | 1
Analog 3V3 LDO | U24 | SOT-23-5 | C2862740 | Texas Instruments | TPS7A2033PDBVR | 1
Digital 3V3 LDO | U25 | SOT-23-5 | C51118 | Diodes Incorporated | AP2112K-3.3TRG1 | 1
16Mbit QSPI flash | U26 | SOIC-8_5.3x5.3mm_P1.27mm | C82317 | Winbond | W25Q16JVSSIQ | 1
8.192MHz CMOS ADC clock | U27 | SMD3225-4P | C7425393 | YXC Crystal Oscillators | OT2JI-111-8.192M | 1
32-pin 0.5mm FPC electrode bank | J1,J2,J3,J4,J5,J6,J7,J8 | FPC_32P_P0.5mm_RA | C2919488 | HDGC | 0.5K-QX-32PWB | 8
USB-C 16-pin receptacle | J9 | USB-C-16P_RA | C165948 | Korean Hroparts Elec | TYPE-C-31-M-12 | 1
CMS1/CMS2/DRL/SHIELD connector | J10 | JST_PH_4P_RA_2.0mm | C265102 | JST | S4B-PH-SM4-TB(LF)(SN) | 1
Isolated 5V battery/data-domain input | J11 | JST_PH_2P_RA_2.0mm | C295747 | JST | S2B-PH-SM4-TB(LF)(SN) | 1
12MHz RP2040 crystal | Y1 | Crystal_SMD_3225-4Pin | C9002 | YXC | X322512MSB4SI | 1
10Mohm electrode bias | R1,R2,R3,R4,R5,R6,R7,R8,R9,R10,R11,R12,R13,R14,R15,R16,R17,R18,R19,R20,R21,R22,R23,R24,R25,R26,R27,R28,R29,R30,R31,R32,R33,R34,R35,R36,R37,R38,R39,R40,R41,R42,R43,R44,R45,R46,R47,R48,R49,R50,R51,R52,R53,R54,R55,R56,R57,R58,R59,R60,R61,R62,R63,R64,R65,R66,R67,R68,R69,R70,R71,R72,R73,R74,R75,R76,R77,R78,R79,R80,R81,R82,R83,R84,R85,R86,R87,R88,R89,R90,R91,R92,R93,R94,R95,R96,R97,R98,R99,R100,R101,R102,R103,R104,R105,R106,R107,R108,R109,R110,R111,R112,R113,R114,R115,R116,R117,R118,R119,R120,R121,R122,R123,R124,R125,R126,R127,R128,R129,R130,R131,R132,R133,R134,R135,R136,R137,R138,R139,R140,R141,R142,R143,R144,R145,R146,R147,R148,R149,R150,R151,R152,R153,R154,R155,R156,R157,R158,R159,R160,R161,R162,R163,R164,R165,R166,R167,R168,R169,R170,R171,R172,R173,R174,R175,R176,R177,R178,R179,R180,R181,R182,R183,R184,R185,R186,R187,R188,R189,R190,R191,R192,R193,R194,R195,R196,R197,R198,R199,R200,R201,R202,R203,R204,R205,R206,R207,R208,R209,R210,R211,R212,R213,R214,R215,R216,R217,R218,R219,R220,R221,R222,R223,R224,R225,R226,R227,R228,R229,R230,R231,R232,R233,R234,R235,R236,R237,R238,R239,R240,R241,R242,R243,R244,R245,R246,R247,R248,R249,R250,R251,R252,R253,R254,R255,R256 | R_0603_1608Metric | C2092526 | Vishay | RCS060310M0FKEA | 256
100kohm electrode series protection | R257,R258,R259,R260,R261,R262,R263,R264,R265,R266,R267,R268,R269,R270,R271,R272,R273,R274,R275,R276,R277,R278,R279,R280,R281,R282,R283,R284,R285,R286,R287,R288,R289,R290,R291,R292,R293,R294,R295,R296,R297,R298,R299,R300,R301,R302,R303,R304,R305,R306,R307,R308,R309,R310,R311,R312,R313,R314,R315,R316,R317,R318,R319,R320,R321,R322,R323,R324,R325,R326,R327,R328,R329,R330,R331,R332,R333,R334,R335,R336,R337,R338,R339,R340,R341,R342,R343,R344,R345,R346,R347,R348,R349,R350,R351,R352,R353,R354,R355,R356,R357,R358,R359,R360,R361,R362,R363,R364,R365,R366,R367,R368,R369,R370,R371,R372,R373,R374,R375,R376,R377,R378,R379,R380,R381,R382,R383,R384,R385,R386,R387,R388,R389,R390,R391,R392,R393,R394,R395,R396,R397,R398,R399,R400,R401,R402,R403,R404,R405,R406,R407,R408,R409,R410,R411,R412,R413,R414,R415,R416,R417,R418,R419,R420,R421,R422,R423,R424,R425,R426,R427,R428,R429,R430,R431,R432,R433,R434,R435,R436,R437,R438,R439,R440,R441,R442,R443,R444,R445,R446,R447,R448,R449,R450,R451,R452,R453,R454,R455,R456,R457,R458,R459,R460,R461,R462,R463,R464,R465,R466,R467,R468,R469,R470,R471,R472,R473,R474,R475,R476,R477,R478,R479,R480,R481,R482,R483,R484,R485,R486,R487,R488,R489,R490,R491,R492,R493,R494,R495,R496,R497,R498,R499,R500,R501,R502,R503,R504,R505,R506,R507,R508,R509,R510,R511,R512 | R_0603_1608Metric | C2989131 | UNI-ROYAL | TC0325F1003T5F | 256
100ohm ADC input isolation | R513,R514,R515,R516,R517,R518,R519,R520,R521,R522,R523,R524,R525,R526,R527,R528 | R_0603_1608Metric | C22775 | UNI-ROYAL | 0603WAF1000T5E | 16
10kohm VCM/CMS network | R529,R530,R531,R532 | R_0603_1608Metric | C25804 | UNI-ROYAL | 0603WAF1002T5E | 4
27ohm USB series | R533,R534 | R_0603_1608Metric | C137753 | Yageo | RC0603FR-0727RL | 2
1Mohm DRL patient-current limit | R535,R536 | R_0603_1608Metric | C105578 | Yageo | RC0603FR-071ML | 2
470kohm DRL feedback | R537 | R_0603_1608Metric | C114622 | Yageo | RC0603FR-07470KL | 1
5.1kohm USB-C CC pulldown | R538,R539 | R_0603_1608Metric | C23186 | UNI-ROYAL | 0603WAF5101T5E | 2
1uF supply decoupling | C1,C2,C3,C4,C5,C6,C7,C8,C9,C10,C11,C12,C13,C14,C15,C16,C17,C18,C19,C20 | C_0603_1608Metric | C15849 | Samsung Electro-Mechanics | CL10A105KB8NNNC | 20
100nF local decoupling | C21,C22,C23,C24,C25,C26,C27,C28,C29,C30,C31,C32,C33,C34,C35,C36,C37,C38,C39,C40,C41,C42,C43,C44,C45,C46,C47,C48,C49,C50,C51,C52,C53,C54,C55,C56,C57,C58,C59,C60 | C_0603_1608Metric | C14663 | Yageo | CC0603KRX7R9BB104 | 40
220nF ADS131M08 CAP bypass | C61 | C_0603_1608Metric | C3894271 | Samsung Electro-Mechanics | CL10B224KO8SFNC | 1
10nF DRL compensation | C62 | C_0603_1608Metric | C57112 | FH | 0603B103K500NT | 1
15pF RP2040 crystal load | C63,C64 | C_0603_1608Metric | C346207 | Samsung Electro-Mechanics | CL10C150JB81PNC | 2

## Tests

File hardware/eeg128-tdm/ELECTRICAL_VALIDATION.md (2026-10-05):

# SPDX-License-Identifier: CERN-OHL-S-2.0
# EEG128-TDM A1 electrical validation plan

## Validation status model

Two independent statuses are used:

```text
theoretical_electrical_review_passed
physical_electrical_lab_validation_passed
```

### Theoretical electrical review

This status may be set to `true` without a fabricated board only when the design has no unresolved theoretical electrical concern and all relevant EDA/datasheet/calculation gates are closed, including:

- complete schematic;
- complete routing and copper zones;
- 0 ERC errors;
- 0 DRC errors;
- 0 unconnected PCB items;
- verified footprints;
- verified ground/reference/power/clock/USB/DRL topology;
- analytically closed TDM settling budget;
- valid ADC/common-mode/headroom calculations;
- no unresolved stability, rating or return-current issue.

This status means **design review passed**, not “measured hardware passed”.

### Physical laboratory validation

`physical_electrical_lab_validation_passed` may be `true` only after measurements on a fabricated board produce the required evidence.

A theoretical review, SPICE simulation, ERC/DRC result or datasheet calculation shall never be represented as a completed physical measurement.

## Release rule

No value in this document is a simulated substitute for a physical measurement.
`noise_settling_validation_passed` and `human_connected_use_authorized` remain
false until a fabricated board has been measured with calibrated equipment.

## Required equipment

- isolated battery supply for the DUT;
- calibrated low-noise differential source or precision DAC + attenuator;
- shorting plugs / low-thermal short for all EEG inputs;
- isolated oscilloscope or differential probe;
- signal generator capable of 10 Hz, 50 Hz and 60 Hz common-mode injection;
- precision DMM;
- current meter/electrometer suitable for the intended leakage-current test range;
- fixture that does not connect the patient-side domain to protective earth.

## Test sequence

### 1. Power-domain bring-up

With no electrodes or human connected:

1. current-limit the isolated 5 V source;
2. verify no rail-to-ground short;
3. verify 3V3A and 3V3D;
4. verify RP2040 1.1 V core rail;
5. verify ADS131M08 CAP and REFIN nodes against the selected datasheet mode;
6. verify 8.192 MHz clock amplitude/frequency;
7. verify DRL output remains bounded with CMS inputs at VCM.

Pass criteria must be recorded with the measured values and instrument IDs.

### 2. TDM settling

Drive one selected differential input with a controlled step while adjacent channels
remain at zero differential input. Capture all eight raw ADS131M08 conversions after
each MUX address transition.

For each logical channel, record conversion indices 1..8 after the switch.

The production discard count is acceptable only if the first retained conversion and
all later retained conversions meet the specified settling error. The current firmware
proposal discards conversions 1..4 and averages 5..8; this is a hypothesis to be
validated, not a guaranteed property.

### 3. Input-referred noise

Short each P/N input pair at the connector fixture to the same low-impedance potential
compatible with the input common-mode range. Acquire at least 60 seconds per channel.

Post-process using the same 0.5–100 Hz BCI band definition used by the product
requirement. Report per-channel RMS and the 50th/95th/worst channel values.

Target:

```text
input-referred RMS noise < 1.5 µV RMS, 0.5–100 Hz
```

Do not claim this target until the physical result passes.

### 4. Crosstalk

Inject a known differential sine wave into one logical channel in each MUX bank.
Terminate all other channels identically. Measure the ratio of the driven-channel
amplitude to every non-driven channel after demultiplexing.

Report the worst adjacent-MUX-position and cross-bank coupling.

### 5. Common-mode rejection

Apply the same common-mode sine to P and N of the selected channel while maintaining
a near-zero differential component. Repeat with DRL disabled and enabled.

Calculate:

```text
CMRR_dB = 20 * log10(V_common_mode_rms / V_equivalent_differential_rms)
```

Any statement such as CMRR > 100 dB must be based on the measured system result,
including fixture limitations.

### 6. 50/60 Hz susceptibility

Run separate common-mode tests at 50 Hz and 60 Hz. Record raw performance before any
software notch filtering. A software notch is not a substitute for analog common-mode
performance.

### 7. DRL stability

Sweep representative electrode/contact impedances and capacitive loads. Verify no
sustained oscillation and no unsafe output under open CMS, shorted CMS, and single
component fault cases included in the engineering risk analysis.

### 8. Isolation/leakage

The project does not self-certify IEC 60601-1. Component isolation ratings such as an
ADuM3160 rating do not establish system Means of Patient Protection.

Perform system-level leakage, dielectric, creepage/clearance and single-fault tests
against the applicable standard and intended-use classification using competent
laboratory procedures before any clinical or patient-connected release.

## Evidence files

Store measured evidence outside the raw-neural-data exclusions using anonymized bench
fixture data only:

```text
hardware/eeg128-tdm/validation/
  equipment.json
  power-rails.json
  settling-summary.json
  noise-summary.json
  crosstalk-summary.json
  cmrr-summary.json
  drl-stability.json
  isolation-lab-reference.json
```

Do not commit human EEG recordings to the public repository.

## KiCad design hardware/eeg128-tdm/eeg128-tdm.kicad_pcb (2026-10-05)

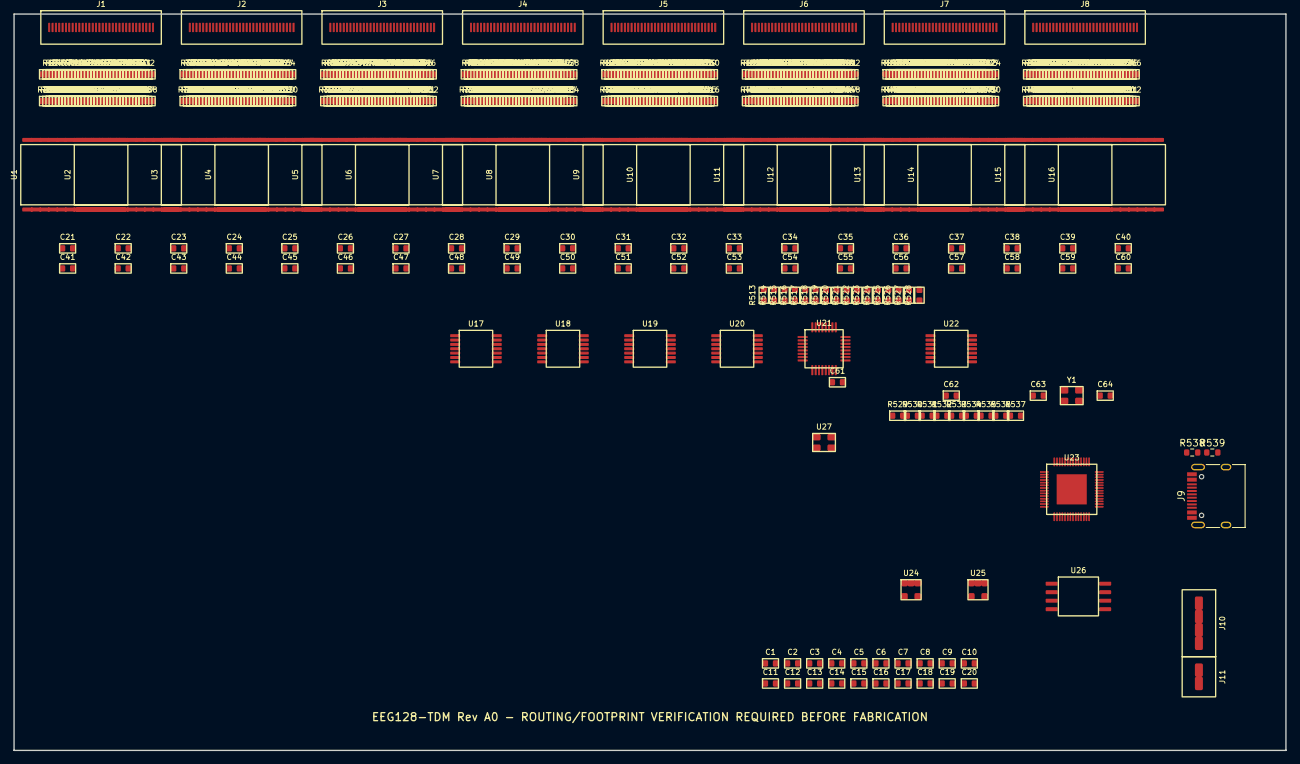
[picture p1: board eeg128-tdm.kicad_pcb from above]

Board: 4 copper layers, 190.0 x 110.0 mm, 642 parts (0 on the bottom side), 604 nets, no tracks yet.

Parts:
C1: C1
C2: C2
C3: C3
C4: C4
C5: C5
C6: C6
C7: C7
C8: C8
C9: C9
C10: C10
C11: C11
C12: C12
C13: C13
C14: C14
C15: C15
C16: C16
C17: C17
C18: C18
C19: C19
C20: C20
C21: C21
C22: C22
C23: C23
C24: C24
C25: C25
C26: C26
C27: C27
C28: C28
C29: C29
C30: C30
C31: C31
C32: C32
C33: C33
C34: C34
C35: C35
C36: C36
C37: C37
C38: C38
C39: C39
C40: C40
C41: C41
C42: C42
C43: C43
C44: C44
C45: C45
C46: C46
C47: C47
C48: C48
C49: C49
C50: C50
C51: C51
C52: C52
C53: C53
C54: C54
C55: C55
C56: C56
C57: C57
C58: C58
C59: C59
C60: C60
C61: C61
C62: C62
C63: C63
C64: C64
J1: J1
J2: J2
J3: J3
J4: J4
J5: J5
J6: J6
J7: J7
J8: J8
J9: TYPE-C-31-M-12; USB_C_Receptacle_HRO_TYPE-C-31-M-12
J10: J10
J11: J11
R1: R1
R2: R2
R3: R3
R4: R4
R5: R5
R6: R6
R7: R7
R8: R8
R9: R9
R10: R10
R11: R11
R12: R12
R13: R13
R14: R14
R15: R15
R16: R16
R17: R17
R18: R18
R19: R19
R20: R20
R21: R21
R22: R22
R23: R23
R24: R24
R25: R25
R26: R26
R27: R27
R28: R28
R29: R29
R30: R30
R31: R31
R32: R32
R33: R33
R34: R34
R35: R35
R36: R36
R37: R37
R38: R38
R39: R39
R40: R40
R41: R41
R42: R42
R43: R43
R44: R44
R45: R45
R46: R46
R47: R47
R48: R48
R49: R49
R50: R50
R51: R51
R52: R52
R53: R53
R54: R54
R55: R55
R56: R56
R57: R57
R58: R58
R59: R59
R60: R60
R61: R61
R62: R62
R63: R63
R64: R64
R65: R65
R66: R66
R67: R67
R68: R68
R69: R69
R70: R70
R71: R71
R72: R72
R73: R73
R74: R74
R75: R75
R76: R76
R77: R77
R78: R78
R79: R79
R80: R80
R81: R81
R82: R82
R83: R83
R84: R84
R85: R85
R86: R86
R87: R87
R88: R88
R89: R89
R90: R90
R91: R91
R92: R92
R93: R93
R94: R94
R95: R95
R96: R96
R97: R97
R98: R98
R99: R99
R100: R100
R101: R101
R102: R102
R103: R103
R104: R104
R105: R105
R106: R106
R107: R107
R108: R108
R109: R109
R110: R110
R111: R111
R112: R112
R113: R113
R114: R114
R115: R115
R116: R116
R117: R117
R118: R118
R119: R119
R120: R120
R121: R121
R122: R122
R123: R123
R124: R124
R125: R125
R126: R126
R127: R127
R128: R128
R129: R129
R130: R130
R131: R131
R132: R132
R133: R133
R134: R134
R135: R135
R136: R136
R137: R137
R138: R138
R139: R139
R140: R140
R141: R141
R142: R142
R143: R143
R144: R144
R145: R145
R146: R146
R147: R147
R148: R148
R149: R149
R150: R150
R151: R151
R152: R152
R153: R153
R154: R154
R155: R155
R156: R156
R157: R157
R158: R158
R159: R159
R160: R160
R161: R161
R162: R162
R163: R163
R164: R164
R165: R165
R166: R166
R167: R167
R168: R168
R169: R169
R170: R170
R171: R171
R172: R172
R173: R173
R174: R174
R175: R175
R176: R176
R177: R177
R178: R178
R179: R179
R180: R180
R181: R181
R182: R182
R183: R183
R184: R184
R185: R185
R186: R186
R187: R187
R188: R188
R189: R189
R190: R190
R191: R191
R192: R192
R193: R193
R194: R194
R195: R195
R196: R196
R197: R197
R198: R198
R199: R199
R200: R200
R201: R201
R202: R202
R203: R203
R204: R204
R205: R205
R206: R206
R207: R207
R208: R208
R209: R209
R210: R210
R211: R211
R212: R212
R213: R213
R214: R214
R215: R215
R216: R216
R217: R217
R218: R218
R219: R219
R220: R220
R221: R221
R222: R222
R223: R223
R224: R224
R225: R225
R226: R226
R227: R227
R228: R228
R229: R229
R230: R230
R231: R231
R232: R232
R233: R233
R234: R234
R235: R235
R236: R236
R237: R237
R238: R238
R239: R239
R240: R240
R241: R241
R242: R242
R243: R243
R244: R244
R245: R245
R246: R246
R247: R247
R248: R248
R249: R249
R250: R250
R251: R251
R252: R252
R253: R253
R254: R254
R255: R255
R256: R256
R257: R257
R258: R258
R259: R259
R260: R260
R261: R261
R262: R262
R263: R263
R264: R264
R265: R265
R266: R266
R267: R267
R268: R268
R269: R269
R270: R270
R271: R271
R272: R272
R273: R273
R274: R274
R275: R275
R276: R276
R277: R277
R278: R278
R279: R279
R280: R280
R281: R281
R282: R282
R283: R283
R284: R284
R285: R285
R286: R286
R287: R287
R288: R288
R289: R289
R290: R290
R291: R291
R292: R292
R293: R293
R294: R294
R295: R295
R296: R296
R297: R297
R298: R298
R299: R299
R300: R300
R301: R301
R302: R302
R303: R303
R304: R304
R305: R305
R306: R306
R307: R307
R308: R308
R309: R309
R310: R310
R311: R311
R312: R312
R313: R313
R314: R314
R315: R315
R316: R316
R317: R317
R318: R318
R319: R319
R320: R320
R321: R321
R322: R322
R323: R323
R324: R324
R325: R325
R326: R326
R327: R327
R328: R328
R329: R329
R330: R330
R331: R331
R332: R332
R333: R333
R334: R334
R335: R335
R336: R336
R337: R337
R338: R338
R339: R339
R340: R340
R341: R341
R342: R342
R343: R343
R344: R344
R345: R345
R346: R346
R347: R347
R348: R348
R349: R349
R350: R350
R351: R351
R352: R352
R353: R353
R354: R354
R355: R355
R356: R356
R357: R357
R358: R358
R359: R359
R360: R360
R361: R361
R362: R362
R363: R363
R364: R364
R365: R365
R366: R366
R367: R367
R368: R368
R369: R369
R370: R370
R371: R371
R372: R372
R373: R373
R374: R374
R375: R375
R376: R376
R377: R377
R378: R378
R379: R379
R380: R380
R381: R381
R382: R382
R383: R383
R384: R384
R385: R385
R386: R386
R387: R387
R388: R388
R389: R389
R390: R390
R391: R391
R392: R392
R393: R393
R394: R394
R395: R395
R396: R396
R397: R397
R398: R398
R399: R399
R400: R400
R401: R401
R402: R402
R403: R403
R404: R404
R405: R405
R406: R406
R407: R407
R408: R408
R409: R409
R410: R410
R411: R411
R412: R412
R413: R413
R414: R414
R415: R415
R416: R416
R417: R417
R418: R418
R419: R419
R420: R420
R421: R421
R422: R422
R423: R423
R424: R424
R425: R425
R426: R426
R427: R427
R428: R428
R429: R429
R430: R430
R431: R431
R432: R432
R433: R433
R434: R434
R435: R435
R436: R436
R437: R437
R438: R438
R439: R439
R440: R440
R441: R441
R442: R442
R443: R443
R444: R444
R445: R445
R446: R446
R447: R447
R448: R448
R449: R449
R450: R450
R451: R451
R452: R452
R453: R453
R454: R454
R455: R455
R456: R456
R457: R457
R458: R458
R459: R459
R460: R460
R461: R461
R462: R462
R463: R463
R464: R464
R465: R465
R466: R466
R467: R467
R468: R468
R469: R469
R470: R470
R471: R471
R472: R472
R473: R473
R474: R474
R475: R475
R476: R476
R477: R477
R478: R478
R479: R479
R480: R480
R481: R481
R482: R482
R483: R483
R484: R484
R485: R485
R486: R486
R487: R487
R488: R488
R489: R489
R490: R490
R491: R491
R492: R492
R493: R493
R494: R494
R495: R495
R496: R496
R497: R497
R498: R498
R499: R499
R500: R500
R501: R501
R502: R502
R503: R503
R504: R504
R505: R505
R506: R506
R507: R507
R508: R508
R509: R509
R510: R510
R511: R511
R512: R512
R513: R513
R514: R514
R515: R515
R516: R516
R517: R517
R518: R518
R519: R519
R520: R520
R521: R521
R522: R522
R523: R523
R524: R524
R525: R525
R526: R526
R527: R527
R528: R528
R529: R529
R530: R530
R531: R531
R532: R532
R533: R533
R534: R534
R535: R535
R536: R536
R537: R537
R538, R539: 5.1k; R_0603_1608Metric
U1: U1
U2: U2
U3: U3
U4: U4
U5: U5
U6: U6
U7: U7
U8: U8
U9: U9
U10: U10
U11: U11
U12: U12
U13: U13
U14: U14
U15: U15
U16: U16
U17: U17
U18: U18
U19: U19
U20: U20
U21: U21
U22: U22
U23: U23
U24: U24
U25: U25
U26: U26
U27: U27
Y1: Y1

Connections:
3V3A: C1.1, C2.1, C3.1, C4.1, C5.1, C6.1, C7.1, C8.1, C9.1, C10.1, C11.1, C12.1, C13.1, C14.1, C15.1, C16.1, C18.1, C21.1, C22.1, C23.1, C24.1, C25.1, C26.1, C27.1, C28.1, C29.1, C30.1, C31.1, C32.1, C33.1, C34.1, C35.1, C36.1, C37.1, C38.1, C39.1, C40.1, C41.1, R529.1, U1.24, U2.24, U3.24, U4.24, U5.24, U6.24, U7.24, U8.24, U9.24, U10.24, U11.24, U12.24, U13.24, U14.24, U15.24, U16.24, U17.4, U18.4, U19.4, U20.4, U21.15, U22.4, U24.5
3V3D: C20.1, C42.1, C44.1, C45.1, C46.1, C47.1, C48.1, C49.1, C53.1, C54.1, C55.1, C56.1, C57.1, C58.1, C59.1, C60.1, U21.26, U23.1, U23.10, U23.22, U23.33, U23.42, U23.43, U23.44, U23.48, U23.49, U25.5, U26.8, U27.1, U27.4
5V_ISO: C17.1, C19.1, J9.A4, J9.A9, J9.B4, J9.B9, J11.1, U24.1, U24.3, U25.1, U25.3
ADC0_N: R514.2, U21.30
ADC0_P: R513.2, U21.29
ADC1_N: R516.2, U21.31
ADC1_P: R515.2, U21.32
ADC2_N: R518.2, U21.2
ADC2_P: R517.2, U21.1
ADC3_N: R520.2, U21.3
ADC3_P: R519.2, U21.4
ADC4_N: R522.2, U21.6
ADC4_P: R521.2, U21.5
ADC5_N: R524.2, U21.7
ADC5_P: R523.2, U21.8
ADC6_N: R526.2, U21.10
ADC6_P: R525.2, U21.9
ADC7_N: R528.2, U21.11
ADC7_P: R527.2, U21.12
ADC_CLKIN: U21.23, U27.3
ADC_CS: U21.17, U23.12
ADC_DIN: U21.21, U23.14
ADC_DOUT: U21.20, U23.11
ADC_DRDY: U21.18, U23.15
ADC_REFIN: C43.1, U21.14
ADC_SCLK: U21.19, U23.13
ADC_SYNC_RESET: U21.16, U23.16
ADS_CAP: C61.1, U21.24
AGND: C1.2, C2.2, C3.2, C4.2, C5.2, C6.2, C7.2, C8.2, C9.2, C10.2, C11.2, C12.2, C13.2, C14.2, C15.2, C16.2, C17.2, C18.2, C19.2, C20.2, C21.2, C22.2, C23.2, C24.2, C25.2, C26.2, C27.2, C28.2, C29.2, C30.2, C31.2, C32.2, C33.2, C34.2, C35.2, C36.2, C37.2, C38.2, C39.2, C40.2, C41.2, C42.2, C43.2, C44.2, C45.2, C46.2, C47.2, C48.2, C49.2, C50.2, C51.2, C52.2, C53.2, C54.2, C55.2, C56.2, C57.2, C58.2, C59.2, C60.2, C61.2, C63.2, C64.2, J9.A1, J9.A12, J9.B1, J9.B12, J11.2, R530.2, R538.2, R539.2, U1.12, U2.12, U3.12, U4.12, U5.12, U6.12, U7.12, U8.12, U9.12, U10.12, U11.12, U12.12, U13.12, U14.12, U15.12, U16.12, U17.11, U18.11, U19.11, U20.11, U21.13, U21.25, U21.28, U22.11, U23.57, U24.2, U25.2, U26.4, U27.2, Y1.2, Y1.4
BANK0_N_BUFFER: R514.1, U17.6, U17.7
BANK0_N_MUX_OUT: U2.1, U17.5
BANK0_P_BUFFER: R513.1, U17.1, U17.2
BANK0_P_MUX_OUT: U1.1, U17.3
BANK1_N_BUFFER: R516.1, U17.13, U17.14
BANK1_N_MUX_OUT: U4.1, U17.12
BANK1_P_BUFFER: R515.1, U17.8, U17.9
BANK1_P_MUX_OUT: U3.1, U17.10
BANK2_N_BUFFER: R518.1, U18.6, U18.7
BANK2_N_MUX_OUT: U6.1, U18.5
BANK2_P_BUFFER: R517.1, U18.1, U18.2
BANK2_P_MUX_OUT: U5.1, U18.3
BANK3_N_BUFFER: R520.1, U18.13, U18.14
BANK3_N_MUX_OUT: U8.1, U18.12
BANK3_P_BUFFER: R519.1, U18.8, U18.9
BANK3_P_MUX_OUT: U7.1, U18.10
BANK4_N_BUFFER: R522.1, U19.6, U19.7
BANK4_N_MUX_OUT: U10.1, U19.5
BANK4_P_BUFFER: R521.1, U19.1, U19.2
BANK4_P_MUX_OUT: U9.1, U19.3
BANK5_N_BUFFER: R524.1, U19.13, U19.14
BANK5_N_MUX_OUT: U12.1, U19.12
BANK5_P_BUFFER: R523.1, U19.8, U19.9
BANK5_P_MUX_OUT: U11.1, U19.10
BANK6_N_BUFFER: R526.1, U20.6, U20.7
BANK6_N_MUX_OUT: U14.1, U20.5
BANK6_P_BUFFER: R525.1, U20.1, U20.2
BANK6_P_MUX_OUT: U13.1, U20.3
BANK7_N_BUFFER: R528.1, U20.13, U20.14
BANK7_N_MUX_OUT: U16.1, U20.12
BANK7_P_BUFFER: R527.1, U20.8, U20.9
BANK7_P_MUX_OUT: U15.1, U20.10
CH000_N_ELECTRODE: J1.17, R258.1
CH000_N_MUX: R2.1, R258.2, U2.9
CH000_P_ELECTRODE: J1.1, R257.1
CH000_P_MUX: R1.1, R257.2, U1.9
CH001_N_ELECTRODE: J1.18, R260.1
CH001_N_MUX: R4.1, R260.2, U2.8
CH001_P_ELECTRODE: J1.2, R259.1
CH001_P_MUX: R3.1, R259.2, U1.8
CH002_N_ELECTRODE: J1.19, R262.1
CH002_N_MUX: R6.1, R262.2, U2.7
CH002_P_ELECTRODE: J1.3, R261.1
CH002_P_MUX: R5.1, R261.2, U1.7
CH003_N_ELECTRODE: J1.20, R264.1
CH003_N_MUX: R8.1, R264.2, U2.6
CH003_P_ELECTRODE: J1.4, R263.1
CH003_P_MUX: R7.1, R263.2, U1.6
CH004_N_ELECTRODE: J1.21, R266.1
CH004_N_MUX: R10.1, R266.2, U2.5
CH004_P_ELECTRODE: J1.5, R265.1
CH004_P_MUX: R9.1, R265.2, U1.5
CH005_N_ELECTRODE: J1.22, R268.1
CH005_N_MUX: R12.1, R268.2, U2.4
CH005_P_ELECTRODE: J1.6, R267.1
CH005_P_MUX: R11.1, R267.2, U1.4
CH006_N_ELECTRODE: J1.23, R270.1
CH006_N_MUX: R14.1, R270.2, U2.3
CH006_P_ELECTRODE: J1.7, R269.1
CH006_P_MUX: R13.1, R269.2, U1.3
CH007_N_ELECTRODE: J1.24, R272.1
CH007_N_MUX: R16.1, R272.2, U2.2
CH007_P_ELECTRODE: J1.8, R271.1
CH007_P_MUX: R15.1, R271.2, U1.2
CH008_N_ELECTRODE: J1.25, R274.1
CH008_N_MUX: R18.1, R274.2, U2.23
CH008_P_ELECTRODE: J1.9, R273.1
CH008_P_MUX: R17.1, R273.2, U1.23
CH009_N_ELECTRODE: J1.26, R276.1
CH009_N_MUX: R20.1, R276.2, U2.22
CH009_P_ELECTRODE: J1.10, R275.1
CH009_P_MUX: R19.1, R275.2, U1.22
CH010_N_ELECTRODE: J1.27, R278.1
CH010_N_MUX: R22.1, R278.2, U2.21
CH010_P_ELECTRODE: J1.11, R277.1
CH010_P_MUX: R21.1, R277.2, U1.21
CH011_N_ELECTRODE: J1.28, R280.1
CH011_N_MUX: R24.1, R280.2, U2.20
CH011_P_ELECTRODE: J1.12, R279.1
CH011_P_MUX: R23.1, R279.2, U1.20
CH012_N_ELECTRODE: J1.29, R282.1
CH012_N_MUX: R26.1, R282.2, U2.19
CH012_P_ELECTRODE: J1.13, R281.1
CH012_P_MUX: R25.1, R281.2, U1.19
CH013_N_ELECTRODE: J1.30, R284.1
CH013_N_MUX: R28.1, R284.2, U2.18
CH013_P_ELECTRODE: J1.14, R283.1
CH013_P_MUX: R27.1, R283.2, U1.18
CH014_N_ELECTRODE: J1.31, R286.1
CH014_N_MUX: R30.1, R286.2, U2.17
CH014_P_ELECTRODE: J1.15, R285.1
CH014_P_MUX: R29.1, R285.2, U1.17
CH015_N_ELECTRODE: J1.32, R288.1
CH015_N_MUX: R32.1, R288.2, U2.16
CH015_P_ELECTRODE: J1.16, R287.1
CH015_P_MUX: R31.1, R287.2, U1.16
CH016_N_ELECTRODE: J2.17, R290.1
CH016_N_MUX: R34.1, R290.2, U4.9
CH016_P_ELECTRODE: J2.1, R289.1
CH016_P_MUX: R33.1, R289.2, U3.9
CH017_N_ELECTRODE: J2.18, R292.1
CH017_N_MUX: R36.1, R292.2, U4.8
CH017_P_ELECTRODE: J2.2, R291.1
CH017_P_MUX: R35.1, R291.2, U3.8
CH018_N_ELECTRODE: J2.19, R294.1
CH018_N_MUX: R38.1, R294.2, U4.7
CH018_P_ELECTRODE: J2.3, R293.1
CH018_P_MUX: R37.1, R293.2, U3.7
CH019_N_ELECTRODE: J2.20, R296.1
CH019_N_MUX: R40.1, R296.2, U4.6
CH019_P_ELECTRODE: J2.4, R295.1
CH019_P_MUX: R39.1, R295.2, U3.6
CH020_N_ELECTRODE: J2.21, R298.1
CH020_N_MUX: R42.1, R298.2, U4.5
CH020_P_ELECTRODE: J2.5, R297.1
CH020_P_MUX: R41.1, R297.2, U3.5
CH021_N_ELECTRODE: J2.22, R300.1
CH021_N_MUX: R44.1, R300.2, U4.4
CH021_P_ELECTRODE: J2.6, R299.1
CH021_P_MUX: R43.1, R299.2, U3.4
CH022_N_ELECTRODE: J2.23, R302.1
CH022_N_MUX: R46.1, R302.2, U4.3
CH022_P_ELECTRODE: J2.7, R301.1
CH022_P_MUX: R45.1, R301.2, U3.3
CH023_N_ELECTRODE: J2.24, R304.1
CH023_N_MUX: R48.1, R304.2, U4.2
CH023_P_ELECTRODE: J2.8, R303.1
CH023_P_MUX: R47.1, R303.2, U3.2
CH024_N_ELECTRODE: J2.25, R306.1
CH024_N_MUX: R50.1, R306.2, U4.23
CH024_P_ELECTRODE: J2.9, R305.1
CH024_P_MUX: R49.1, R305.2, U3.23
CH025_N_ELECTRODE: J2.26, R308.1
CH025_N_MUX: R52.1, R308.2, U4.22
CH025_P_ELECTRODE: J2.10, R307.1
CH025_P_MUX: R51.1, R307.2, U3.22
CH026_N_ELECTRODE: J2.27, R310.1
CH026_N_MUX: R54.1, R310.2, U4.21
CH026_P_ELECTRODE: J2.11, R309.1
CH026_P_MUX: R53.1, R309.2, U3.21
CH027_N_ELECTRODE: J2.28, R312.1
CH027_N_MUX: R56.1, R312.2, U4.20
CH027_P_ELECTRODE: J2.12, R311.1
CH027_P_MUX: R55.1, R311.2, U3.20
CH028_N_ELECTRODE: J2.29, R314.1
CH028_N_MUX: R58.1, R314.2, U4.19
CH028_P_ELECTRODE: J2.13, R313.1
CH028_P_MUX: R57.1, R313.2, U3.19
CH029_N_ELECTRODE: J2.30, R316.1
CH029_N_MUX: R60.1, R316.2, U4.18
CH029_P_ELECTRODE: J2.14, R315.1
CH029_P_MUX: R59.1, R315.2, U3.18
CH030_N_ELECTRODE: J2.31, R318.1
CH030_N_MUX: R62.1, R318.2, U4.17
CH030_P_ELECTRODE: J2.15, R317.1
CH030_P_MUX: R61.1, R317.2, U3.17
CH031_N_ELECTRODE: J2.32, R320.1
CH031_N_MUX: R64.1, R320.2, U4.16
CH031_P_ELECTRODE: J2.16, R319.1
CH031_P_MUX: R63.1, R319.2, U3.16
CH032_N_ELECTRODE: J3.17, R322.1
CH032_N_MUX: R66.1, R322.2, U6.9
CH032_P_ELECTRODE: J3.1, R321.1
CH032_P_MUX: R65.1, R321.2, U5.9
CH033_N_ELECTRODE: J3.18, R324.1
CH033_N_MUX: R68.1, R324.2, U6.8
CH033_P_ELECTRODE: J3.2, R323.1
CH033_P_MUX: R67.1, R323.2, U5.8
CH034_N_ELECTRODE: J3.19, R326.1
CH034_N_MUX: R70.1, R326.2, U6.7
CH034_P_ELECTRODE: J3.3, R325.1
CH034_P_MUX: R69.1, R325.2, U5.7
CH035_N_ELECTRODE: J3.20, R328.1
CH035_N_MUX: R72.1, R328.2, U6.6
CH035_P_ELECTRODE: J3.4, R327.1
CH035_P_MUX: R71.1, R327.2, U5.6
CH036_N_ELECTRODE: J3.21, R330.1
CH036_N_MUX: R74.1, R330.2, U6.5
CH036_P_ELECTRODE: J3.5, R329.1
CH036_P_MUX: R73.1, R329.2, U5.5
CH037_N_ELECTRODE: J3.22, R332.1
CH037_N_MUX: R76.1, R332.2, U6.4
CH037_P_ELECTRODE: J3.6, R331.1
CH037_P_MUX: R75.1, R331.2, U5.4
CH038_N_ELECTRODE: J3.23, R334.1
CH038_N_MUX: R78.1, R334.2, U6.3
CH038_P_ELECTRODE: J3.7, R333.1
CH038_P_MUX: R77.1, R333.2, U5.3
CH039_N_ELECTRODE: J3.24, R336.1
CH039_N_MUX: R80.1, R336.2, U6.2
CH039_P_ELECTRODE: J3.8, R335.1
CH039_P_MUX: R79.1, R335.2, U5.2
CH040_N_ELECTRODE: J3.25, R338.1
CH040_N_MUX: R82.1, R338.2, U6.23
CH040_P_ELECTRODE: J3.9, R337.1
CH040_P_MUX: R81.1, R337.2, U5.23
CH041_N_ELECTRODE: J3.26, R340.1
CH041_N_MUX: R84.1, R340.2, U6.22
CH041_P_ELECTRODE: J3.10, R339.1
CH041_P_MUX: R83.1, R339.2, U5.22
CH042_N_ELECTRODE: J3.27, R342.1
CH042_N_MUX: R86.1, R342.2, U6.21
CH042_P_ELECTRODE: J3.11, R341.1
CH042_P_MUX: R85.1, R341.2, U5.21
CH043_N_ELECTRODE: J3.28, R344.1
CH043_N_MUX: R88.1, R344.2, U6.20
CH043_P_ELECTRODE: J3.12, R343.1
CH043_P_MUX: R87.1, R343.2, U5.20
CH044_N_ELECTRODE: J3.29, R346.1
CH044_N_MUX: R90.1, R346.2, U6.19
CH044_P_ELECTRODE: J3.13, R345.1
CH044_P_MUX: R89.1, R345.2, U5.19
CH045_N_ELECTRODE: J3.30, R348.1
CH045_N_MUX: R92.1, R348.2, U6.18
CH045_P_ELECTRODE: J3.14, R347.1
CH045_P_MUX: R91.1, R347.2, U5.18
CH046_N_ELECTRODE: J3.31, R350.1
CH046_N_MUX: R94.1, R350.2, U6.17
CH046_P_ELECTRODE: J3.15, R349.1
CH046_P_MUX: R93.1, R349.2, U5.17
CH047_N_ELECTRODE: J3.32, R352.1
CH047_N_MUX: R96.1, R352.2, U6.16
CH047_P_ELECTRODE: J3.16, R351.1
CH047_P_MUX: R95.1, R351.2, U5.16
CH048_N_ELECTRODE: J4.17, R354.1
CH048_N_MUX: R98.1, R354.2, U8.9
CH048_P_ELECTRODE: J4.1, R353.1
CH048_P_MUX: R97.1, R353.2, U7.9
CH049_N_ELECTRODE: J4.18, R356.1
CH049_N_MUX: R100.1, R356.2, U8.8
CH049_P_ELECTRODE: J4.2, R355.1
CH049_P_MUX: R99.1, R355.2, U7.8
CH050_N_ELECTRODE: J4.19, R358.1
CH050_N_MUX: R102.1, R358.2, U8.7
CH050_P_ELECTRODE: J4.3, R357.1
CH050_P_MUX: R101.1, R357.2, U7.7
CH051_N_ELECTRODE: J4.20, R360.1
CH051_N_MUX: R104.1, R360.2, U8.6
CH051_P_ELECTRODE: J4.4, R359.1
CH051_P_MUX: R103.1, R359.2, U7.6
CH052_N_ELECTRODE: J4.21, R362.1
CH052_N_MUX: R106.1, R362.2, U8.5
CH052_P_ELECTRODE: J4.5, R361.1
CH052_P_MUX: R105.1, R361.2, U7.5
CH053_N_ELECTRODE: J4.22, R364.1
CH053_N_MUX: R108.1, R364.2, U8.4
CH053_P_ELECTRODE: J4.6, R363.1
CH053_P_MUX: R107.1, R363.2, U7.4
CH054_N_ELECTRODE: J4.23, R366.1
CH054_N_MUX: R110.1, R366.2, U8.3
CH054_P_ELECTRODE: J4.7, R365.1
CH054_P_MUX: R109.1, R365.2, U7.3
CH055_N_ELECTRODE: J4.24, R368.1
CH055_N_MUX: R112.1, R368.2, U8.2
CH055_P_ELECTRODE: J4.8, R367.1
CH055_P_MUX: R111.1, R367.2, U7.2
CH056_N_ELECTRODE: J4.25, R370.1
CH056_N_MUX: R114.1, R370.2, U8.23
CH056_P_ELECTRODE: J4.9, R369.1
CH056_P_MUX: R113.1, R369.2, U7.23
CH057_N_ELECTRODE: J4.26, R372.1
CH057_N_MUX: R116.1, R372.2, U8.22
CH057_P_ELECTRODE: J4.10, R371.1
CH057_P_MUX: R115.1, R371.2, U7.22
CH058_N_ELECTRODE: J4.27, R374.1
CH058_N_MUX: R118.1, R374.2, U8.21
CH058_P_ELECTRODE: J4.11, R373.1
CH058_P_MUX: R117.1, R373.2, U7.21
CH059_N_ELECTRODE: J4.28, R376.1
CH059_N_MUX: R120.1, R376.2, U8.20
CH059_P_ELECTRODE: J4.12, R375.1
CH059_P_MUX: R119.1, R375.2, U7.20
CH060_N_ELECTRODE: J4.29, R378.1
CH060_N_MUX: R122.1, R378.2, U8.19
CH060_P_ELECTRODE: J4.13, R377.1
CH060_P_MUX: R121.1, R377.2, U7.19
CH061_N_ELECTRODE: J4.30, R380.1
CH061_N_MUX: R124.1, R380.2, U8.18
CH061_P_ELECTRODE: J4.14, R379.1
CH061_P_MUX: R123.1, R379.2, U7.18
CH062_N_ELECTRODE: J4.31, R382.1
CH062_N_MUX: R126.1, R382.2, U8.17
CH062_P_ELECTRODE: J4.15, R381.1
CH062_P_MUX: R125.1, R381.2, U7.17
CH063_N_ELECTRODE: J4.32, R384.1
CH063_N_MUX: R128.1, R384.2, U8.16
CH063_P_ELECTRODE: J4.16, R383.1
CH063_P_MUX: R127.1, R383.2, U7.16
CH064_N_ELECTRODE: J5.17, R386.1
CH064_N_MUX: R130.1, R386.2, U10.9
CH064_P_ELECTRODE: J5.1, R385.1
CH064_P_MUX: R129.1, R385.2, U9.9
CH065_N_ELECTRODE: J5.18, R388.1
CH065_N_MUX: R132.1, R388.2, U10.8
CH065_P_ELECTRODE: J5.2, R387.1
CH065_P_MUX: R131.1, R387.2, U9.8
CH066_N_ELECTRODE: J5.19, R390.1
CH066_N_MUX: R134.1, R390.2, U10.7
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

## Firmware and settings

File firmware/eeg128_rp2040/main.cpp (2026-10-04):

// SPDX-License-Identifier: CERN-OHL-S-2.0
#include <array>
#include <cstddef>
#include <cstdint>
#include <cstring>
#include <limits>

#include "pico/stdlib.h"
#include "hardware/dma.h"
#include "hardware/gpio.h"
#include "hardware/irq.h"
#include "hardware/spi.h"
#include "hardware/sync.h"


namespace {

// -----------------------------------------------------------------------------
// Board mapping: RP2040 QFN56 / SPI1 valid pin group.
// -----------------------------------------------------------------------------

spi_inst_t *const kAdcSpi = spi1;

constexpr uint kPinSpiMiso = 8;   // SPI1 RX
constexpr uint kPinAdcCs = 9;     // GPIO-controlled SPI1 CSn
constexpr uint kPinSpiSck = 10;   // SPI1 SCK
constexpr uint kPinSpiMosi = 11;  // SPI1 TX

constexpr uint kPinAdcDrdy = 12;
constexpr uint kPinAdcSyncReset = 13;

constexpr uint kPinMuxA0 = 2;
constexpr uint kPinMuxA1 = 3;
constexpr uint kPinMuxA2 = 4;
constexpr uint kPinMuxA3 = 5;
constexpr uint kPinMuxEnable = 6;

// -----------------------------------------------------------------------------
// Acquisition model.
// -----------------------------------------------------------------------------

constexpr unsigned kBankCount = 8;
constexpr unsigned kChannelsPerBank = 16;
constexpr unsigned kEegChannels = 128;

constexpr unsigned kDiscardConversions = 4;
constexpr unsigned kKeepConversions = 4;
constexpr unsigned kConversionsPerSlot =
    kDiscardConversions + kKeepConversions;

static_assert(kConversionsPerSlot == 8);

constexpr unsigned kAdcFrameWords = 10;  // response + 8 channels + CRC
constexpr unsigned kAdcWordBytes = 4;
constexpr unsigned kAdcFrameBytes = kAdcFrameWords * kAdcWordBytes;

constexpr uint32_t kLogicalRateHz = 250;
constexpr uint32_t kCalibrationFrames = 500;

// -----------------------------------------------------------------------------
// ADS131M08 configuration.
//
// CLKIN is a dedicated 8.192-MHz CMOS oscillator connected to pin 23.
// CLOCK:
//   channels enabled = 0xFF00
//   XTAL_DIS = 1 because CLKIN is externally driven
//   EXTREF_EN = 0, internal 1.2-V reference
//   OSR = 000 = 128
//   PWR = 10 = HR
//
// MODE:
//   RESET status clear
//   WLENGTH = 11 = 32-bit sign-extended conversion words
//   TIMEOUT = 1
//   DRDY_FMT = 1 = active-low pulse
//
// GAIN1/GAIN2:
//   PGAGAIN = 010 = gain 4 for every channel.
// -----------------------------------------------------------------------------

constexpr uint8_t kRegMode = 0x02;
constexpr uint8_t kRegClock = 0x03;
constexpr uint8_t kRegGain1 = 0x04;
constexpr uint8_t kRegGain2 = 0x05;

constexpr uint16_t kClock32kSpsExternalClock = 0xFF82;
constexpr uint16_t kMode32BitSignExtend = 0x0311;
constexpr uint16_t kGainAll4 = 0x2222;

// SPI is intentionally well below the ADS131M08 digital-interface maximum.
constexpr uint32_t kSpiBaudHz = 12'000'000;

// -----------------------------------------------------------------------------
// Existing P1/P2 transport format.
// -----------------------------------------------------------------------------

constexpr uint32_t kBciMagic = 0x31494342u;  // "BCI1" little-endian
constexpr uint16_t kBciProtocol = 0x0100;
constexpr uint16_t kBciHeaderBytes = 128;

constexpr uint32_t kFlagEegPresent = 1u << 0;
constexpr uint32_t kFlagTimestampValid = 1u << 3;
constexpr uint32_t kFlagCalibrated = 1u << 5;

#pragma pack(push, 1)

struct BciPacketHeader {
    uint32_t magic;
    uint16_t protocol_version;
    uint16_t header_bytes;
    uint32_t packet_bytes;
    uint32_t sequence;
    uint64_t timestamp_ns;
    uint32_t flags;
    uint32_t status;
    uint32_t eeg_channel_mask[4];
    uint32_t meg_channel_mask[4];
    uint16_t eeg_channel_count;
    uint16_t meg_channel_count;
    uint16_t fnirs_long_count;
    uint16_t fnirs_short_count;
    uint8_t fnirs_wavelength_count;
    uint8_t sample_format;
    uint16_t reserved0;
    uint8_t reserved[44];
    uint32_t payload_crc32c;
    uint32_t header_crc32c;
};

struct BciFastPacket {
    BciPacketHeader header;
    int32_t eeg[kEegChannels];
    int32_t meg[kEegChannels];
};

#pragma pack(pop)

static_assert(sizeof(BciPacketHeader) == 128);
static_assert(sizeof(BciFastPacket) == 1152);

struct Calibration {
    int64_t offset;
    int32_t gain_q30;
};

// -----------------------------------------------------------------------------
// State.
// -----------------------------------------------------------------------------

alignas(4) uint8_t g_spi_tx[kAdcFrameBytes] = {};
alignas(4) uint8_t g_spi_rx[kAdcFrameBytes] = {};

int g_dma_tx = -1;
int g_dma_rx = -1;

volatile bool g_spi_busy = false;
volatile uint8_t g_mux_position = 0;
volatile uint8_t g_sample_in_slot = 0;

std::array<int64_t, kBankCount> g_accumulation = {};
std::array<int32_t, kEegChannels> g_eeg_frame = {};
std::array<Calibration, kEegChannels> g_calibration = {};
std::array<int64_t, kEegChannels> g_calibration_sum = {};

uint32_t g_calibration_frames = 0;
bool g_calibration_complete = false;
uint32_t g_packet_sequence = 0;

// -----------------------------------------------------------------------------
// CRC32C / Castagnoli.
// -----------------------------------------------------------------------------

uint32_t Crc32c(
    uint32_t initial,
    const void *data,
    std::size_t length
) {
    const auto *p = static_cast<const uint8_t *>(data);
    uint32_t crc = ~initial;

    for (std::size_t i = 0; i < length; ++i) {
        crc ^= p[i];
        for (unsigned bit = 0; bit < 8; ++bit) {
            const uint32_t mask =
                static_cast<uint32_t>(
                    -static_cast<int32_t>(crc & 1u)
                );
            crc = (crc >> 1u) ^ (0x82F63B78u & mask);
        }
    }
    return ~crc;
}

uint64_t TimestampNs() {
    return static_cast<uint64_t>(time_us_64()) * 1000ull;
}

int32_t BigEndianSigned32(const uint8_t *p) {
    const uint32_t value =
        (static_cast<uint32_t>(p[0]) << 24u) |
        (static_cast<uint32_t>(p[1]) << 16u) |
        (static_cast<uint32_t>(p[2]) << 8u) |
        static_cast<uint32_t>(p[3]);
    return static_cast<int32_t>(value);
}

// -----------------------------------------------------------------------------
// MUX.
// -----------------------------------------------------------------------------

void SetMuxEnabled(bool enabled) {
    // CD74HC4067 enable is active low.
    gpio_put(kPinMuxEnable, enabled ? 0 : 1);
}

void SelectMux(uint8_t channel) {
    SetMuxEnabled(false);

    gpio_put(kPinMuxA0, (channel >> 0u) & 1u);
    gpio_put(kPinMuxA1, (channel >> 1u) & 1u);
    gpio_put(kPinMuxA2, (channel >> 2u) & 1u);
    gpio_put(kPinMuxA3, (channel >> 3u) & 1u);

    busy_wait_us_32(2);
    SetMuxEnabled(true);
}

// -----------------------------------------------------------------------------
// ADS131M08 configuration.
// -----------------------------------------------------------------------------

void AdcCs(bool asserted) {
    gpio_put(kPinAdcCs, asserted ? 0 : 1);
}

void WriteRegister24(uint8_t address, uint16_t value) {
    // WREG format: 011a aaaa annn nnnn, n=0 for one register.
    const uint16_t command =
        static_cast<uint16_t>(0x6000u | (static_cast<uint16_t>(address) << 7u));

    // During startup the ADC uses default 24-bit communication words.
    // A complete normal frame is still clocked so no pending conversion frame
    // is accidentally truncated.
    uint8_t frame[30] = {};
    frame[0] = static_cast<uint8_t>(command >> 8u);
    frame[1] = static_cast<uint8_t>(command);
    frame[2] = 0;

    frame[3] = static_cast<uint8_t>(value >> 8u);
    frame[4] = static_cast<uint8_t>(value);
    frame[5] = 0;

    AdcCs(true);
    spi_write_blocking(kAdcSpi, frame, sizeof(frame));
    AdcCs(false);
    busy_wait_us_32(10);
}

void SynchronizeAdc() {
    // 2 us at 8.192 MHz is about 16 CLKIN cycles and remains far below
    // the 2048-CLKIN reset threshold.
    gpio_put(kPinAdcSyncReset, 0);
    busy_wait_us_32(2);
    gpio_put(kPinAdcSyncReset, 1);
}

void ConfigureAdc() {
    AdcCs(false);
    gpio_put(kPinAdcSyncReset, 1);
    sleep_ms(20);

    WriteRegister24(kRegClock, kClock32kSpsExternalClock);
    WriteRegister24(kRegGain1, kGainAll4);
    WriteRegister24(kRegGain2, kGainAll4);

    // MODE is written last because it changes the communication word length.
    WriteRegister24(kRegMode, kMode32BitSignExtend);

    sleep_ms(2);
    SynchronizeAdc();
}

// -----------------------------------------------------------------------------
// Calibration.
// -----------------------------------------------------------------------------

int32_t ApplyCalibration(unsigned channel, int32_t raw) {
    const Calibration &cal = g_calibration[channel];
    const int64_t centered = static_cast<int64_t>(raw) - cal.offset;
    const int64_t corrected =
        (centered * static_cast<int64_t>(cal.gain_q30)) >> 30;

    if (corrected > std::numeric_limits<int32_t>::max()) {
        return std::numeric_limits<int32_t>::max();
    }
    if (corrected < std::numeric_limits<int32_t>::min()) {
        return std::numeric_limits<int32_t>::min();
    }
    return static_cast<int32_t>(corrected);
}

void UpdateStartupOffsetCalibration() {
    if (g_calibration_complete) {
        return;
    }

    for (unsigned channel = 0; channel < kEegChannels; ++channel) {
        g_calibration_sum[channel] += g_eeg_frame[channel];
    }

    ++g_calibration_frames;
    if (g_calibration_frames < kCalibrationFrames) {
        return;
    }

    for (unsigned channel = 0; channel < kEegChannels; ++channel) {
        g_calibration[channel].offset =
            g_calibration_sum[channel] / static_cast<int64_t>(kCalibrationFrames);
        g_calibration[channel].gain_q30 = 1 << 30;
    }

    g_calibration_complete = true;
}

// -----------------------------------------------------------------------------
// Transport.
// -----------------------------------------------------------------------------

void EmitPacket() {
    static BciFastPacket packet;
    std::memset(&packet, 0, sizeof(packet));

    packet.header.magic = kBciMagic;
    packet.header.protocol_version = kBciProtocol;
    packet.header.header_bytes = kBciHeaderBytes;
    packet.header.packet_bytes = sizeof(packet);
    packet.header.sequence = g_packet_sequence++;
    packet.header.timestamp_ns = TimestampNs();
    packet.header.flags =
        kFlagEegPresent |
        kFlagTimestampValid |
        (g_calibration_complete ? kFlagCalibrated : 0u);

    for (uint32_t &word : packet.header.eeg_channel_mask) {
        word = 0xFFFFFFFFu;
    }
    packet.header.eeg_channel_count = kEegChannels;
    packet.header.sample_format = 1;  // S32 little endian

    for (unsigned channel = 0; channel < kEegChannels; ++channel) {
        packet.eeg[channel] =
            ApplyCalibration(channel, g_eeg_frame[channel]);
    }

    packet.header.payload_crc32c =
        Crc32c(
            0,
            reinterpret_cast<const uint8_t *>(&packet) + kBciHeaderBytes,
            sizeof(packet) - kBciHeaderBytes
        );

    packet.header.header_crc32c =
        Crc32c(
            0,
            &packet.header,
            offsetof(BciPacketHeader, header_crc32c)
        );

    const auto *bytes = reinterpret_cast<const uint8_t *>(&packet);
    for (std::size_t i = 0; i < sizeof(packet); ++i) {
        stdio_putchar_raw(bytes[i]);
    }
}

// -----------------------------------------------------------------------------
// SPI DMA.
// -----------------------------------------------------------------------------

void StartSpiDma() {
    if (g_spi_busy) {
        return;
    }
    g_spi_busy = true;
    std::memset(g_spi_tx, 0, sizeof(g_spi_tx));

    AdcCs(true);

    dma_channel_set_read_addr(g_dma_tx, g_spi_tx, false);
    dma_channel_set_write_addr(g_dma_rx, g_spi_rx, false);
    dma_channel_set_trans_count(g_dma_rx, kAdcFrameBytes, false);
    dma_channel_set_trans_count(g_dma_tx, kAdcFrameBytes, false);

    dma_start_channel_mask(
        (1u << static_cast<unsigned>(g_dma_rx)) |
        (1u << static_cast<unsigned>(g_dma_tx))
    );
}

void ProcessAdcFrame() {
    if (g_sample_in_slot >= kDiscardConversions) {
        for (unsigned bank = 0; bank < kBankCount; ++bank) {
            const std::size_t byte_offset = (1u + bank) * kAdcWordBytes;
            g_accumulation[bank] += BigEndianSigned32(&g_spi_rx[byte_offset]);
        }
    }

    ++g_sample_in_slot;
    if (g_sample_in_slot < kConversionsPerSlot) {
        return;
    }

    for (unsigned bank = 0; bank < kBankCount; ++bank) {
        const unsigned logical_channel =
            bank * kChannelsPerBank + g_mux_position;

        g_eeg_frame[logical_channel] =
            static_cast<int32_t>(
                g_accumulation[bank] /
                static_cast<int64_t>(kKeepConversions)
            );
        g_accumulation[bank] = 0;
    }

    g_sample_in_slot = 0;
    ++g_mux_position;

    if (g_mux_position >= kChannelsPerBank) {
        g_mux_position = 0;
        UpdateStartupOffsetCalibration();
        EmitPacket();
    }

    SelectMux(g_mux_position);
    SynchronizeAdc();
}

void DmaIrqHandler() {
    const uint32_t rx_mask = 1u << static_cast<unsigned>(g_dma_rx);
    if ((dma_hw->ints0 & rx_mask) == 0) {
        return;
    }

    dma_hw->ints0 = rx_mask;
    dma_channel_wait_for_finish_blocking(g_dma_tx);
    AdcCs(false);
    g_spi_busy = false;
    ProcessAdcFrame();
}

void DrdyIrq(uint gpio, uint32_t events) {
    if (
        gpio == kPinAdcDrdy &&
        (events & GPIO_IRQ_EDGE_FALL) != 0u
    ) {
        StartSpiDma();
    }
}

// -----------------------------------------------------------------------------
// Hardware startup.
// -----------------------------------------------------------------------------

void InitOutput(uint pin, bool value) {
    gpio_init(pin);
    gpio_set_dir(pin, GPIO_OUT);
    gpio_put(pin, value);
}

void InitHardware() {
    InitOutput(kPinAdcCs, true);
    InitOutput(kPinAdcSyncReset, true);
    InitOutput(kPinMuxA0, false);
    InitOutput(kPinMuxA1, false);
    InitOutput(kPinMuxA2, false);
    InitOutput(kPinMuxA3, false);
    InitOutput(kPinMuxEnable, true);

    gpio_init(kPinAdcDrdy);
    gpio_set_dir(kPinAdcDrdy, GPIO_IN);

    spi_init(kAdcSpi, kSpiBaudHz);
    spi_set_format(
        kAdcSpi,
        8,
        SPI_CPOL_0,
        SPI_CPHA_1,
        SPI_MSB_FIRST
    );

    gpio_set_function(kPinSpiMiso, GPIO_FUNC_SPI);
    gpio_set_function(kPinSpiSck, GPIO_FUNC_SPI);
    gpio_set_function(kPinSpiMosi, GPIO_FUNC_SPI);

    g_dma_tx = dma_claim_unused_channel(true);
    g_dma_rx = dma_claim_unused_channel(true);

    dma_channel_config tx = dma_channel_get_default_config(g_dma_tx);
    channel_config_set_transfer_data_size(&tx, DMA_SIZE_8);
    channel_config_set_dreq(&tx, spi_get_dreq(kAdcSpi, true));
    channel_config_set_read_increment(&tx, true);
    channel_config_set_write_increment(&tx, false);
    dma_channel_configure(
        g_dma_tx,
        &tx,
        &spi_get_hw(kAdcSpi)->dr,
        g_spi_tx,
        0,
        false
    );

    dma_channel_config rx = dma_channel_get_default_config(g_dma_rx);
    channel_config_set_transfer_data_size(&rx, DMA_SIZE_8);
    channel_config_set_dreq(&rx, spi_get_dreq(kAdcSpi, false));
    channel_config_set_read_increment(&rx, false);
    channel_config_set_write_increment(&rx, true);
    dma_channel_configure(
        g_dma_rx,
        &rx,
        g_spi_rx,
        &spi_get_hw(kAdcSpi)->dr,
        0,
        false
    );

    dma_channel_set_irq0_enabled(g_dma_rx, true);
    irq_set_exclusive_handler(DMA_IRQ_0, DmaIrqHandler);
    irq_set_enabled(DMA_IRQ_0, true);

    gpio_set_irq_enabled_with_callback(
        kPinAdcDrdy,
        GPIO_IRQ_EDGE_FALL,
        true,
        &DrdyIrq
    );
}

}  // namespace


int main() {
    stdio_init_all();
    sleep_ms(1200);

    for (Calibration &cal : g_calibration) {
        cal.offset = 0;
        cal.gain_q30 = 1 << 30;
    }

    InitHardware();
    SelectMux(0);
    ConfigureAdc();

    g_mux_position = 0;
    g_sample_in_slot = 0;
    g_accumulation.fill(0);
    SelectMux(0);
    SynchronizeAdc();

    while (true) {
        __wfi();
    }
}

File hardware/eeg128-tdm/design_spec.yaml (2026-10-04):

# SPDX-License-Identifier: CERN-OHL-S-2.0
revision: A0

board:
  name: eeg128-tdm
  width_mm: 190
  height_mm: 110
  thickness_mm: 1.6
  copper_outer_um: 35
  copper_inner_um: 18
  layers:
    - "F.Cu: components, electrode inputs, analog acquisition and shortest local digital routes"
    - "In1.Cu: continuous ground return plane; no arbitrary analog/digital moat cuts"
    - "In2.Cu: controlled 3V3A / 3V3D / VCM power distribution"
    - "B.Cu: controller-side digital, USB and low-sensitivity routing"
  domain_control:
    method: placement_and_return_current_management
    ground_plane: continuous
    adc_boundary_review: required

acquisition:
  logical_channels: 128
  differential_conductors: 256
  banks: 8
  mux_positions_per_bank: 16
  adc_channels: 8
  adc_rate_sps: 32000
  target_logical_rate_sps: 250
  adc_clock_hz: 8192000
  adc_clock_source: "U27 external CMOS oscillator"
  adc_osr: 128
  adc_power_mode: HR
  adc_pga_gain: 4
  discard_conversions_after_mux_switch: 4
  keep_conversions_per_slot: 4

controller:
  mcu: RP2040
  spi_controller: SPI1
  pins:
    mux_a0_gpio: 2
    mux_a1_gpio: 3
    mux_a2_gpio: 4
    mux_a3_gpio: 5
    mux_enable_gpio: 6
    spi_miso_gpio: 8
    spi_cs_gpio: 9
    spi_sck_gpio: 10
    spi_mosi_gpio: 11
    adc_drdy_gpio: 12
    adc_sync_reset_gpio: 13

components:
  mux: CD74HC4067M96
  buffer: TLV9064IPWR
  adc: ADS131M08IPBSR
  controller: RP2040
  adc_clock: OT2JI-111-8.192M
  drl_vcm: OPA4171AIPWR

connectors:
  electrode_banks: 8
  contacts_per_bank: 32
  mapping: "pins 1..16 = CH(16*b+0..15)+; pins 17..32 = CH(16*b+0..15)-"
  subject_aux:
    j10_pin1: CMS1
    j10_pin2: CMS2
    j10_pin3: DRL
    j10_pin4: SHIELD
  isolated_supply:
    j11_pin1: 5V_ISO
    j11_pin2: ISO_GND

safety:
  patient_connected_release: prohibited
  required_power: isolated_battery_domain
  usb: isolated_only_when_electrodes_attached
  release_status_file: RELEASE_STATUS.json
  compliance_document: ../../docs/SAFETY_COMPLIANCE.md

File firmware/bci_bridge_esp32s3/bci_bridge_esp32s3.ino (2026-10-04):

// SPDX-License-Identifier: CERN-OHL-S-2.0
#include <Arduino.h>
#include <esp_timer.h>
#include <stddef.h>
#include <stdint.h>
#include <string.h>

static constexpr uint32_t BCI_SAMPLE_RATE_HZ = 250;
static constexpr size_t BCI_ANALOG_CHANNELS = 8;
static constexpr size_t BCI_DIGITAL_CHANNELS = 4;
static constexpr uint8_t kAnalogPins[BCI_ANALOG_CHANNELS] = {1,2,3,4,5,6,7,8};
static constexpr uint8_t kDigitalPins[BCI_DIGITAL_CHANNELS] = {11,12,13,14};

static constexpr uint32_t BCI_PACKET_MAGIC = 0x31494342UL;
static constexpr uint16_t BCI_PROTOCOL_VERSION = 0x0100;
static constexpr uint16_t BCI_HEADER_BYTES = 128;
static constexpr uint8_t BCI_SAMPLE_S32_LE = 1;
static constexpr uint32_t BCI_FLAG_EEG_PRESENT = 1UL << 0;
static constexpr uint32_t BCI_FLAG_TIMESTAMP_VALID = 1UL << 3;
static constexpr uint32_t BCI_FLAG_CALIBRATED = 1UL << 5;
static constexpr uint32_t BCI_FLAG_BRIDGE_PAYLOAD = 1UL << 15;

#pragma pack(push, 1)
struct bci_packet_header_t {
    uint32_t magic;
    uint16_t protocol_version, header_bytes;
    uint32_t packet_bytes, sequence;
    uint64_t timestamp_ns;
    uint32_t flags, status;
    uint32_t eeg_channel_mask[4], meg_channel_mask[4];
    uint16_t eeg_channel_count, meg_channel_count, fnirs_long_count, fnirs_short_count;
    uint8_t fnirs_wavelength_count, sample_format;
    uint16_t reserved0;
    uint8_t reserved[44];
    uint32_t payload_crc32c, header_crc32c;
};
struct bci_bridge_payload_t {
    int32_t analog[BCI_ANALOG_CHANNELS];
    uint32_t digital_bits;
    uint32_t sample_counter;
};
struct bci_bridge_packet_t {
    bci_packet_header_t header;
    bci_bridge_payload_t payload;
};
#pragma pack(pop)

static_assert(sizeof(bci_packet_header_t) == 128);
static_assert(sizeof(bci_bridge_packet_t) == 168);

static uint32_t crc32c(uint32_t initial, const void *data, size_t n) {
    auto p = static_cast<const uint8_t *>(data);
    uint32_t crc = ~initial;
    while (n--) {
        crc ^= *p++;
        for (unsigned i=0;i<8;i++) {
            const uint32_t mask = static_cast<uint32_t>(-static_cast<int32_t>(crc & 1U));
            crc = (crc >> 1U) ^ (0x82F63B78UL & mask);
        }
    }
    return ~crc;
}

static uint32_t sequence_no = 0;
static uint32_t sample_counter = 0;

static void buildPacket(bci_bridge_packet_t &p) {
    memset(&p, 0, sizeof(p));
    p.header.magic = BCI_PACKET_MAGIC;
    p.header.protocol_version = BCI_PROTOCOL_VERSION;
    p.header.header_bytes = BCI_HEADER_BYTES;
    p.header.packet_bytes = sizeof(p);
    p.header.sequence = sequence_no++;
    p.header.timestamp_ns = static_cast<uint64_t>(esp_timer_get_time()) * 1000ULL;
    p.header.flags = BCI_FLAG_EEG_PRESENT | BCI_FLAG_TIMESTAMP_VALID | BCI_FLAG_CALIBRATED | BCI_FLAG_BRIDGE_PAYLOAD;
    p.header.eeg_channel_mask[0] = 0xFF;
    p.header.eeg_channel_count = BCI_ANALOG_CHANNELS;
    p.header.sample_format = BCI_SAMPLE_S32_LE;
    for (size_t i=0;i<BCI_ANALOG_CHANNELS;i++) p.payload.analog[i] = analogRead(kAnalogPins[i]);
    for (size_t i=0;i<BCI_DIGITAL_CHANNELS;i++) if (digitalRead(kDigitalPins[i]) == LOW) p.payload.digital_bits |= 1UL << i;
    p.payload.sample_counter = sample_counter++;
    p.header.payload_crc32c = crc32c(0, &p.payload, sizeof(p.payload));
    p.header.header_crc32c = crc32c(0, &p.header, offsetof(bci_packet_header_t, header_crc32c));
}

void setup() {
    analogReadResolution(12);
    for (auto pin : kAnalogPins) pinMode(pin, INPUT);
    for (auto pin : kDigitalPins) pinMode(pin, INPUT_PULLUP);
    Serial.begin(921600);
    delay(250);
}

void loop() {
    static int64_t next_us = esp_timer_get_time();
    static bci_bridge_packet_t p;
    constexpr int64_t period_us = 1000000LL / BCI_SAMPLE_RATE_HZ;
    const int64_t now = esp_timer_get_time();
    if (now < next_us) return;
    next_us += period_us;
    buildPacket(p);
    Serial.write(reinterpret_cast<const uint8_t *>(&p), sizeof(p));
}

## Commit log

2026-10-04 Publish project landing page
2026-10-04 Publish config/99-bci-esp32.rules
2026-10-04 Publish DMA ring protocol
2026-10-04 Publish synthetic DMA simulator
2026-10-04 Pin validation toolchain classes
2026-10-04 Add JLCPCB BOM
    [BOM.csv]
2026-10-04 Add JLCPCB CPL
    [CPL.csv]
2026-10-04 Add hardware safety and regulatory compliance policy
2026-10-04 Complete JLCPCB BOM with clocking, DRL and decoupling
    [BOM.csv]
2026-10-04 Complete JLCPCB placement list
    [CPL.csv]
2026-10-04 Add complete logical hardware netlist
    [NETLIST.csv]
2026-10-04 Add KiCad 8 schematic connectivity specification
    [eeg128-tdm.kicad_sch]
2026-10-04 Add KiCad 8 project
2026-10-04 Add KiCad 8 four-layer placement and net board
    [eeg128-tdm.kicad_pcb]
2026-10-05 Strengthen regulatory and isolation safety guidance
2026-10-05 Strengthen defensive-publication legal framework
2026-10-05 Add component identity and assembly source audit
2026-10-05 Add deterministic KiCad schematic generator
2026-10-05 Remove unused schematic generator expression
2026-10-05 Smoke-test deterministic schematic generation
2026-10-05 Document deterministic schematic generation
2026-10-05 Require schematic generator in EDA source set
2026-10-05 Fix schematic generator lint
2026-10-05 Fix generated-schematic CI regex
2026-10-05 Refresh manifest for schematic CI fix
2026-10-05 Add deterministic EDA materialization workflow
2026-10-05 Materialize generated KiCad connectivity schematic
    [eeg128-tdm.generated.kicad_sch]
2026-10-05 Couple generated EDA to release manifest
2026-10-05 Materialize generated KiCad schematic and release manifest
2026-10-05 Refresh manifest when native KiCad validation changes
2026-10-05 Add native KiCad 8 parse, ERC and DRC validation
2026-10-05 Fix KiCad root sheet instance path
2026-10-05 Verify regenerated KiCad 8 artifact
2026-10-05 Run native KiCad validation on every push
2026-10-05 Align generated library symbols with KiCad 8 schema
2026-10-05 Diagnose KiCad primary and generated schematic parsing
2026-10-05 Remove KiCad 8-incompatible embedded font fields
    [eeg128-tdm.kicad_sch]
2026-10-05 Replace invalid primary schematic with generated KiCad 8 schematic
    [eeg128-tdm.kicad_sch]
2026-10-05 Materialize generated schematic as primary KiCad source
2026-10-05 Verify materialized KiCad primary source
2026-10-05 Enable KiCad schematic parser trace in native validation
2026-10-05 Record native KiCad 8 audit findings
2026-10-05 Record native KiCad ERC and DRC findings
2026-10-05 Update final audit with native KiCad findings
2026-10-05 Repair A1 power clock USB and decoupling connectivity
2026-10-05 Install KiCad footprint library for A1 corrections
2026-10-05 Emit explicit no-connect markers for unused schematic pins
2026-10-05 Map KiCad USB-C footprint by canonical Type-C pin names
2026-10-05 Make A1 ground merge idempotent
2026-10-05 Fix generated schematic no-connect syntax
2026-10-05 Report native KiCad ERC counts from regenerated schematic
2026-10-05 Use verified KiCad SOIC-24W footprints for all EEG MUXes
2026-10-05 Preserve MUX footprints and correct pad orientation in place
2026-10-05 Eliminate remaining A1 footprint and placement shorts
2026-10-05 Apply manufacturable RP2040 fine-pitch clearance
2026-10-05 Add USB-C CC pulldowns to production BOM
    [BOM.csv]
2026-10-05 Add USB-C CC pulldowns to placement file
    [CPL.csv]
2026-10-05 Validate expanded A1 BOM reference set
2026-10-05 Allow normalized A1 component set in schematic generator
2026-10-05 Materialize normalized A1 PCB connectivity before schematic generation
2026-10-05 Add In1 ground plane and deterministic VCM power preroutes
2026-10-05 Require normalized 642-component A1 schematic
2026-10-05 Verify normalized A1 KiCad source
2026-10-05 Snap generated KiCad schematic endpoints to electrical grid
2026-10-05 Remove unsafe deterministic power preroutes from A1
2026-10-05 Align EEG input resistor banks to MUX channel topology
2026-10-05 Expose A1 prepared board and unconnected-net diagnostics
2026-10-05 Add deterministic KiCad symbol-library generator
2026-10-05 Register local NBFM1_A0 KiCad symbol library
2026-10-05 Materialize local KiCad symbol library
2026-10-05 Verify current EDA release tree
2026-10-05 Mark native schematic ERC clean
2026-10-05 Report current A1 preroute copper and DRC metrics
2026-10-05 Stitch A1 ground pads to continuous In1 plane
2026-10-05 Revert ineffective ground stitch experiment
2026-10-05 Report A1 DRC error samples for routing correction
2026-10-05 Align mux escapes and refill ground plane after routing
2026-11-01 Auto-analyze failed trusted CI KiCad and autoroute runs with Gemini from main
2026-11-01 Add offline redaction, failed-job filtering and no-release diagnostics tests
2026-11-01 Pin Gemini post-failure workflow, analysis script and tests into full tracked-file integrity manifest
2026-11-01 Repair preexisting main manifest drift and pin working Gemini 3.8 failure diagnostics
2026-11-01 Fix KiCad source integrity metrics for tab-indented pcbnew boards

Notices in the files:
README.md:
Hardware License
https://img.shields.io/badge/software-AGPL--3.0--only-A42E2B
